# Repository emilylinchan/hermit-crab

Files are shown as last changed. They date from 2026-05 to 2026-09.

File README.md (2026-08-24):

# Hermit Crab 🦀

A WiFi-controlled quadruped walking robot built from scratch — custom 3D-printed chassis, PCB, and ESP32 firmware driving 8 servo leg joints with an OLED face. The long-term goal is an autonomous platform with computer-vision-guided motion planning, built up through multiple hardware and firmware iterations.

<p align="center">
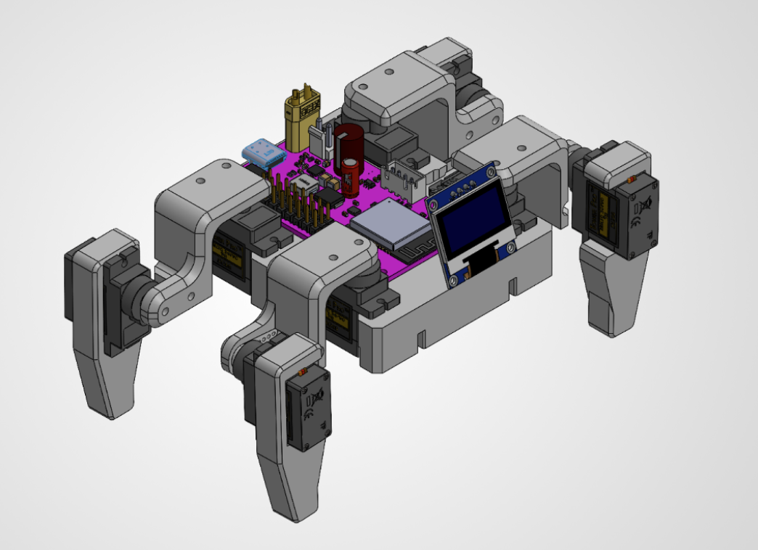
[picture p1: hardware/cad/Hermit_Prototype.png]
Hermit Crab prototype
  
</p>

## Project Structure

```
hermit-crab/
├── firmware/                       
|    ├── main/      # Main ESP32 firmware project
|    └── tests/     # Standalone bring-up sketches (servo calibration, WiFi AP)
|
└── hardware/
    ├── cad/        # Chassis and leg CAD models
    └── pcb/
        ├── drc/    # Design Rule Check for JLC PCB manufacturer
        ├── v1/     # Version 1 board files
        └── v2/     # Version 2 board files
```

- **Firmware** — architecture, controls, and calibration are documented in [`firmware/README.md`](firmware/README.md)
- **Hardware** — component selection and power-system design documented in [`hardware/pcb/Hermit_Hardware_Design.pdf`](hardware/pcb/Hermit_Hardware_Design.pdf)
- **PCB v1** — complete; documented in [`hardware/pcb/v1/README.md`](hardware/pcb/v1/README.md)
- **PCB v2** — in progress; documented in [`hardware/pcb/v2/README.md`](hardware/pcb/v2/README.md)

🎬 **[Watch the video demo of firmware testing](https://youtu.be/UnXPqfklwHU)**

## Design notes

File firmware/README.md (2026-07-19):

# Hermit Crab — Firmware

ESP32 firmware for the Hermit Crab quadruped: C++ (Arduino framework) on FreeRTOS, with a fully data-driven motion engine.

## Hardware Interface

What the firmware expects to be wired up:

| Peripheral | Config |
|---|---|
| Servos | 8× MG90D on pins 13, 14, 23, 16, 17, 18, 19, 33 — order: R1 R2 L1 L2 R4 R3 L3 L4 |
| OLED | SSD1306 128×64 over I2C (SDA 21 / SCL 22, addr `0x3C`) |
| WiFi | AP mode, SSID `HermitCrab`, UI at `http://192.168.0.1` |
| Serial | 115200 baud CLI |

**NOTE:** The MG90D's full 500–2500 µs pulse range spans 270° of travel. The firmware attaches the servos at 833–2167 µs, trimming ~333 µs per side so that the code's 0–180° range maps onto the physically centered 180° of the servo. Keyframes also stay in the 0–180 units and the extreme ends of travel are never commanded.

## Architecture

Four FreeRTOS tasks across both cores. Commands from any source funnel through a single depth-1 queue (`xQueueOverwrite` — newest command always wins), and all physical servo motion flows through one interpolator task.

```mermaid
flowchart TD
    A[Web browser<br/>WiFi AP 192.168.0.1] --> W[webServerTask<br/>Core 0]
    B[Serial monitor<br/>115200 baud CLI] --> S[serialTask<br/>Core 0]
    W --> Q[commandQueue<br/>depth 1, overwrite]
    S --> Q
    Q --> M[motionTask<br/>Core 1, priority 2]
    M -->|setServoTarget| I[interpolatorTask<br/>Core 1, priority 3]
    I --> SV[8× servos<br/>50 Hz PWM]
    M --> O[OLED face<br/>displayMutex]
```

| Task | Core | Priority | Job |
|---|---|---|---|
| `webServerTask` | 0 | 1 | Serves the web UI, parses `/cmd`, `/motor`, `/status` |
| `serialTask` | 0 | 1 | Serial CLI: movements, direct motor control, subtrim |
| `motionTask` | 1 | 2 | The state machine — plays sequences by setting servo targets |
| `interpolatorTask` | 1 | 3 | 50 Hz tick that glides every servo toward its target at a capped speed |

### Single-Owner Servo Model

There is no servo mutex, by design. `servoTarget[]` may be written from any task via `setServoTarget()`, but **servo hardware is written only by `interpolatorTask`** — the single owner. Poses and gaits never touch the hardware; they declare where servos should *end up*, and the interpolator moves them there at up to `servoMaxSpeed` (600 deg/s default), producing smooth motion and eliminating write races structurally instead of locking around them.

The one exception is boot: `setServoImmediate()` snaps all servos to 90° once, staggered 5 ms apart to spread inrush current, before any task exists.

### Data-Driven Motion

Every movement is a table of `Keyframe`s — 8 target angles (or `NC` = "no change") plus a duration — wrapped in a `Sequence` with playback flags:

```cpp
static const Keyframe WAVE_FRAMES[] = {
  //  R1   R2   L1   L2   R4   R3   L3   L4    ms
  { {135,  45,  45, 135,   0, 180,   0, 180}, 200 },  // stand
  { {170,  NC,  NC, 165,  NC,  NC,  NC,  NC}, 250 },  // shift weight back-right
  ...
};
const Sequence SEQ_WAVE = { WAVE_FRAMES, FRAME_COUNT(WAVE_FRAMES), 3, 4, false, true, false };
```

Sequence flags control playback: `loopStart`/`repeatCount` replay a section, `isGait` marks continuous held-state cycles (walking, turning), `standAtEnd` glides back to the stand posture when finished (used by one-shot poses), and `sticky` parks in the state after completion (used by static poses). Two generic engines (`playPose`, `playGaitCycle`) play everything; a lookup table maps states to sequences.

**Adding a new movement** touches four data tables and zero functions: a state in the `MovementState` enum, a frames array + `Sequence` in `movement-sequences.cpp`, a row in `SEQUENCE_TABLE`, a row in `COMMAND_TABLE`, and a row in `FACE_TABLE`.

### Interruption and Safety

Animations poll the command queue *inside* their frame delays (`interruptibleDelay` for poses, `pressingCheck` for gaits), so a new command preempts mid-animation instead of waiting for the sequence to finish. Aborted gaits recover gracefully to the stand posture.

The web D-pad drives gaits as **held** commands: the browser re-sends the command every 200 ms while the button is held, and a firmware hold watchdog (`HOLD_TIMEOUT_MS`, 600 ms) stops the robot if refreshes stop arriving — a closed browser, a dropped WiFi link, or a finger sliding off the button can't leave the robot walking into a wall. The web UI adds its own layers: pointer capture so release always registers, plus auto-stop when the tab is hidden or loses focus. Serial gait commands are not held and run until `stop`.

## Controls

### Web UI

Connect to the `HermitCrab` WiFi access point and open `http://192.168.0.1`. The interface has a hold-to-drive D-pad, a stop button, one-tap pose buttons, and per-servo sliders for direct motor control.

### Serial CLI (115200 baud)

```
rest, stand, walk, back, left, right,     movement & pose commands
wave, dance, swim, point, pushup, bow,
cute, freaky, worm, shake, shrug,
dead, crab, stop

<m> <angle>        direct motor (e.g. "3 90")
all <angle>        all motors at once
subtrim            show trim values
subtrim <m> <v>    trim motor m by v degrees (-90..+90)
subtrim reset      zero all trims
subtrim save       print a code line to paste back into the sketch
```

### HTTP API

| Endpoint | Description |
|---|---|
| `GET /cmd?c=<command>` | Any command string from the table above |
| `GET /motor?i=<0-7>&a=<0-180>` | Direct motor write |
| `GET /status` | JSON state + live servo positions |

`/status` returns live interpolated positions, intended as the hook for future scripting and the Raspberry Pi / ROS 2 bridge:

```json
{"state":7,"name":"wave","pos":[135,45,45,135,0,180,0,80]}
```

## Calibration

Mechanical assembly never puts every leg segment at a perfect neutral, so each servo has a **subtrim** offset applied at hardware-write time. The workflow: run the robot, adjust live over serial (`subtrim 3 -4`), then `subtrim save` prints the `servoSubtrim[8]` initializer to paste into the sketch permanently.

## Directory Layout

```
firmware/
├── main/
|    ├── main.ino                    # Tasks, state machine, interpolator, web/serial handlers
|    ├── movement-sequences.h        # Servo layout, state enum, Keyframe/Sequence model
|    ├── movement-sequences.cpp      # All pose & gait data tables + the playback engines
|    ├── web.h                       # The web UI (single self-contained HTML page in PROGMEM)
|    └── face-bitmaps.h / .cpp       # OLED face bitmaps (X-macro list, image2cpp output)
|
└── tests/
     ├── servo/mg90d-servo-test.ino  # Standalone sketch for bring-up/calibration of servos
     └── wifi/wifi-test.ino          # Standalone sketch to verify the ESP32 WiFi AP in isolation
```

## Hardware Status
 
The firmware currently runs on an **ESP32 WROOM-32E dev board** for testing while the custom ESP32-S3 PCB is being built. The pin assignments above reflect the dev board wiring and will change when the firmware moves to the S3 board.
 
## Roadmap
 
- Orientation sensing (IMU) once PCB is done
- Forward kinematics for foot-position telemetry over `/status`
- Raspberry Pi 5 + ROS 2 / MoveIt 2 as a high-level planner, with the ESP32 as a real-time joint-space executor
- Camera + computer-vision-guided motion planning

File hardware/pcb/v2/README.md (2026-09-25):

# Hermit V2 PCB

## Background

Version 1 successfully validated the core power architecture. The ESP32 was able to be powered from both USB and battery, and the 3.3 V rail reliably powered all I2C peripherals. A temporary block-terminal test point inserted in the battery input path also enabled current consumption measurements, which matched the original design expectations. As a result, no functional changes to the power system were required.

### Issues with V1

- ESP32 received power, but was not recognized as a valid device by USB.
- Data lines were not properly impedance matched (the USB D+ and D− signals must be routed as a 90Ω ± 10% differential pair).

## Changes in V2

- Added power indicator LEDs for immediate visual confirmation of each power rail, eliminating the need to probe with a DMM during bring-up.
- Removed the temporary block-terminal current measurement point used during V1 validation.
- Optimized component placement and routing to reduce the overall PCB footprint.
- Moved the ESP32 further inward on the board so the antenna no longer overhangs the PCB as it did in V1, improving mechanical integration and simplifying the CAD enclosure design.
- Used layer stackup information from our fabricator ([JLC PCB](https://jlcpcb.com/impedance)) and Altium's trace impedance calculator to determine the exact trace width and spacing needed to meet USB impedance requirements.

## Altium Layouts

<table>
  <tr>
    <td align="center">
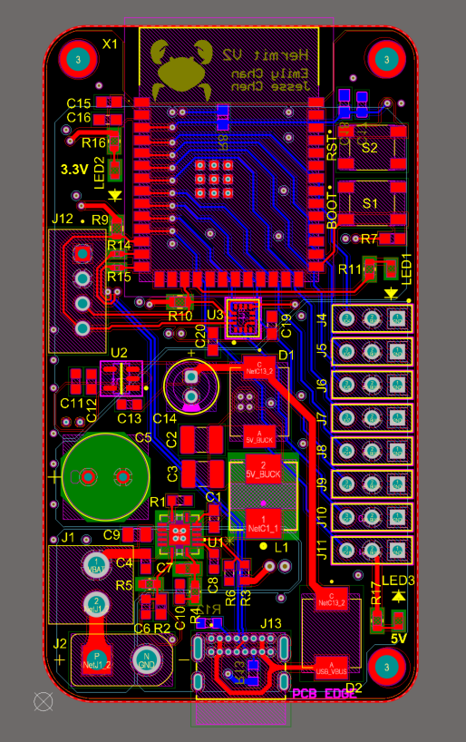
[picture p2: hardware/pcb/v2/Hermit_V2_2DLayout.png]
2D Layout
      <br>
      2D Layout
    </td>
    <td align="center">
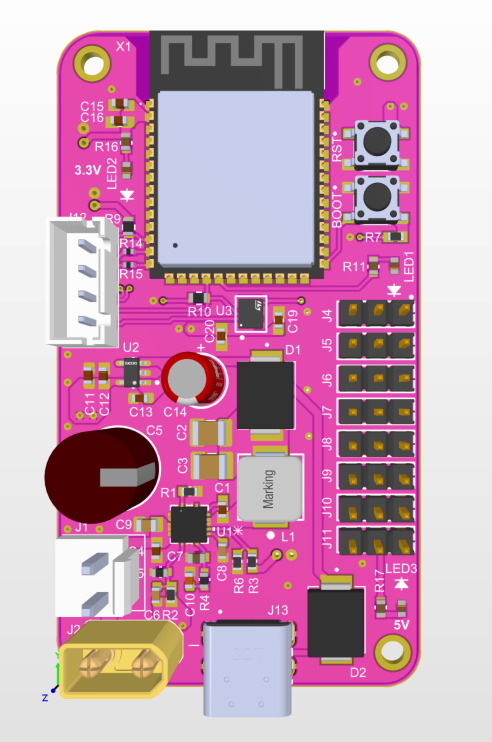
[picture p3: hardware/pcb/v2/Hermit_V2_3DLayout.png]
3D Layout
      <br>
      3D Layout
    </td>
  </tr>
</table>

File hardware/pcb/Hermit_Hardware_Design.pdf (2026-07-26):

Hermit Crab — Hardware Design · 1

# Hermit Crab

## Hardware Design Documentation

Emily Chan and Jesse Chen
Quadruped robotics platform · ESP32-S3 · 2S LiPo power system

This document captures the power-electronics and control-hardware design decisions behind the Hermit Crab robot. It begins with the servo motors and battery that define the system's load and energy budget, then walks through the 5 V buck converter and its component selection, the 3.3 V logic supply, the ESP32-S3 microcontroller and its USB programming interface, power source arbitration between battery and USB, and the onboard IMU and OLED display.

## 1. Servo Motors — MG90D Digital Micro Servo

The eight leg joints are driven by MG90D digital micro servos. Their peak current draw sets the sizing of the 5 V buck converter, and their PWM control scheme defines the timing requirements for the ESP32-S3.

Electrical Characteristics

- Operating voltage: 4.8 – 6.6 V
- Static current: 5 – 6 mA
- No-load current: 220 mA
- Stall (blocking) current: 800 mA + 10% ≈ 880 mA

PWM Control

- Rotation direction: CCW
- Pulse width range: 500 – 2500 µs – Origin position: 500 µs
– Neutral position: 1500 µs
– End position: 2500 µs
- Operating frequency: 50 – 330 Hz
– Standard application: 50 Hz (20 ms PWM frame)
- The output angle is set by the high-time of the pulse — the ESP32-S3 generates one PWM channel per servo.

Impact on Power Design

Eight servos, each with an 880 mA stall current, produce a worst-case load of approximately 7.0 A. Allowing additional headroom for the ESP32 and other onboard peripherals, the 5 V rail is designed to supply up to 8 A. In practice, all eight servos are unlikely to stall simultaneously, so the typical current draw is significantly lower; however, the power rail is sized to accommodate this worst-case scenario.

## 2. Battery — Fytoo 2S 2000 mAh (XT30)

The robot is powered by a Fytoo 2S 2000 mAh 15C LiPo pack. This higher capacity compared to a smaller pack allows for significantly greater runtime, while its 15C rating still supplies the servo load with wide margin. The trade-off is added weight, which the chassis and leg servos must carry.

Specifications

- Configuration: 2S1P / 7.4 V nominal / 2 cell
- Capacity: 2000 mAh
- Continuous discharge: 15C
- Discharge plug: XT30
- Weight: 89g

Discharge Headroom

The C-rating sets the maximum safe current the pack can source:

- Continuous: 15C × 2.0 Ah ≈ 30 A
This is well above the ~8 A worst-case system load, so the pack is never current-limited and voltage sag under a stall event is minimal.

Runtime Calculations

Stored energy at nominal voltage:

- 2.0 Ah × 7.4 V ≈ 14.8 Wh
Runtime is estimated as usable capacity divided by average current draw. Using 80% usable capacity (to avoid over-discharging the cells) and adding ~0.3 A for logic and sensors, the runtime across load scenarios is:
- Typical gait (~400 mA/servo avg): ~3.5 A total → roughly 27 – 28 minutes.
- All servos no-load (220 mA each): ~2.1 A total → roughly 45 minutes.
- Worst case, all servos stalled (880 mA each): ~7.3 A total → roughly 13 minutes.

## 3. 5 V Buck Converter — TPS54821

The main system rail is generated by a TPS54821 synchronous step-down converter, sized to drive eight servos plus the logic electronics from a 2S LiPo battery.

Power Budget

- Servos: 8 × 1 A peak
- ESP32-S3: 500 mA peak during Wi-Fi transmission spikes
- IMU and OLED: negligible

Design Requirements

- Input range: 6 V – 8.4 V (2S LiPo)
- Output: 5 V @ 8 A

Datasheet: https://www.ti.com/lit/ds/symlink/tps54821.pdf

Reference Schematic

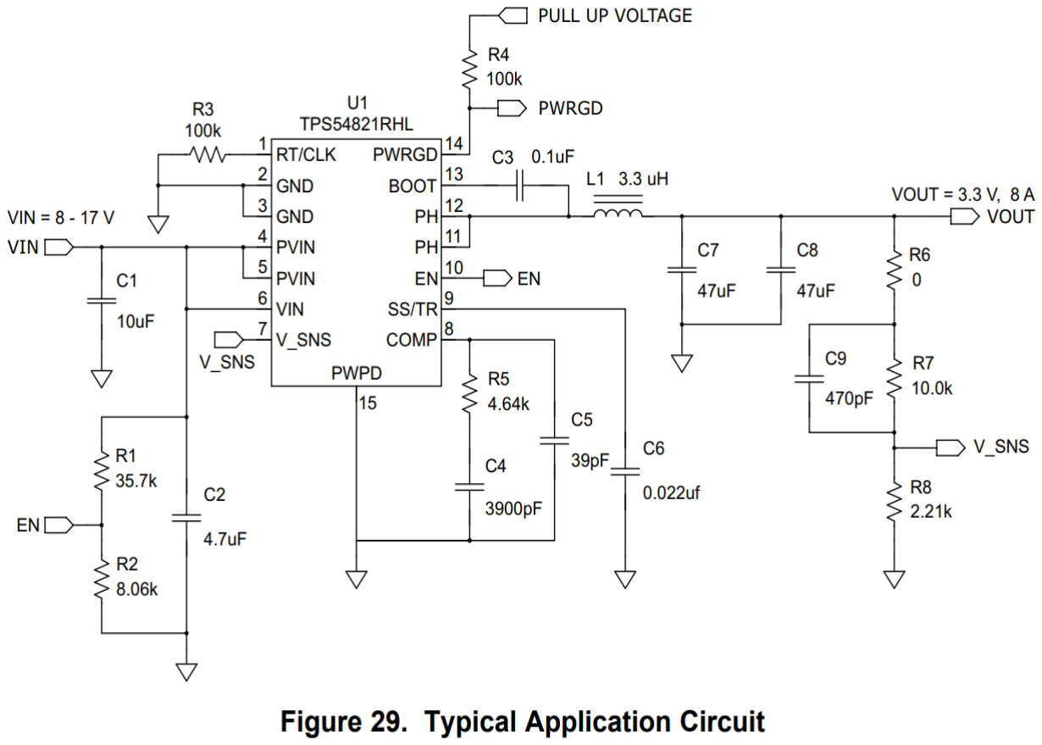
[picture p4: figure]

TPS54821 buck converter, modelled on the datasheet application example.

Design Summary

Parameter | Value
Output voltage (Vout) | 5 V
Output current | 8 A
Transient response, 4 A load step (ΔIout) | ΔVout = 0.35 V (7%)
Input voltage (Vin) | 6.0 V (empty) 7.4 V (nominal) 8.4 V (fully charged)
Reference voltage | 0.6 V
Output voltage ripple | 33 mV p-p
Start input voltage (rising Vin) | 6.528 V
Stop input voltage (falling Vin) | 6.193 V
Operating frequency | 480 kHz

Switching Frequency

The switching frequency sets a trade-off between size and efficiency:

- Higher frequency → smaller solution size, since lower inductance and output-capacitor values can be used.
- Lower frequency → higher efficiency and less heat.
A moderate 480 kHz switching frequency was selected to balance compact size against efficient operation, matching the datasheet application example.

Reference: https://www.ti.com/lit/wp/slyy193c/slyy193c.pdf

Undervoltage Lockout (UVLO)

Undervoltage lockout matters for the 2S LiPo pack because over-discharging causes permanent capacity loss. The turn-on and turn-off thresholds are set by the R1/R2 divider on the EN pin.

Turn-on threshold — 6.528 V

- The converter will not begin switching until the battery voltage rises above this level.
- Prevents the converter from attempting to run when the battery is too low. Turn-off threshold — 6.193 V
- Once running, the converter keeps switching until the battery falls below this level.
- Shuts down below the threshold to avoid undervoltage stress on the cells.
Hysteresis window
- The gap between the two thresholds stops the converter from rapidly cycling on and off when the battery hovers near the limit.
- Set by the R1/R2 divider feeding the EN pin: R1 = 35.7 kΩ, R2 = 8.06 kΩ (matching the application example).

Reference: https://www.ti.com/document-viewer/lit/html/SSZTAG8

Bootstrap Capacitor

- A 0.1 µF ceramic capacitor (C3) is connected between the BOOT and PH pins for proper high-side gate drive.
- An X5R or better dielectric grade is recommended.

Slow-Start Capacitor

The slow-start capacitor sets the minimum time for the output to ramp to its nominal value at power-up.

For this design the soft-start time is not critical, since the 2 × 47 µF output capacitance charges to 5 V without drawing much current. Using the TPS54821 slow-start current of Iss = 2.3 µA and a target ramp of 6 ms:

C6 = 22 nF was selected (matching the application example).

Output Inductor

KIND is the coefficient describing inductor ripple current relative to maximum output current; typical values range from 0.1 to 0.3. A value of 0.3 was chosen here.

The calculated minimum is L1 = 1.76 µH. A larger standard 3.3 µH value was selected to lower ripple current and match the application example.

Reference: https://www.ti.com/lit/ta/ssztap6/ssztap6.pdf

Output Capacitor

The output capacitor must supply load transients until the control loop responds:

- The regulator typically needs two or more clock cycles to detect a load change and adjust the duty cycle.

- The output capacitance must supply the current difference over those two cycles while limiting output voltage sag to a tolerable level.

The calculated minimum is Co = 47.6 µF. To account for capacitance de-rating from aging, temperature, and DC bias, a conservative 2 × 47 µF was chosen.

Input Capacitor

The TPS54821 requires a high-quality X5R or X7R ceramic decoupling capacitor of at least 4.7 µF effective capacitance on each of the PVIN and VIN pins.

C1 = 10 µF and C2 = 4.7 µF were selected (matching the application example).
Output Voltage Feedback Divider
The R7/R8 divider sets the output voltage:

With R7 = 10 kΩ, R8 calculates to 1.36 kΩ, rounded to R8 = 1.37 kΩ — the nearest standard 1% value.

Compensation Network

An RC network stabilizes the converter's internal error amplifier and feedback control loop.

- Compensation resistor (Rc = R5 = 4.64 kΩ): in series with the compensation capacitor to the COMP pin; sets mid-band gain, loop crossover frequency, and transient response.
- Compensation capacitor (Cc = C4 = 3900 pF): creates a low-frequency pole that boosts phase margin at crossover for stability.
- High-frequency capacitor (Cp = C5 = 39 pF): from COMP to ground; adds a high-frequency pole to attenuate switching noise and gain spikes.
- Feed-forward capacitor (Cff = C9 = 470 pF): across the top feedback resistor; adds a phase-lead zero that improves phase margin and transient response and attenuates high-frequency output noise.
Because the operating conditions closely match the application example, the same compensation values were used.

## 4. 3.3 V Logic Supply — AP2112K-3.3TRG1

A low-dropout regulator generates the 3.3 V logic rail from the 5 V system supply.

Specifications

- Input: 2.5 – 6 V
- Output: 3.3 V @ 0.6 A
- Enable: tie pin 3 (EN) to VIN for normal operation (logic high).

Datasheet: https://www.diodes.com/assets/Datasheets/AP2112.pdf

## 5. Microcontroller — ESP32-S3-WROOM

The ESP32-S3-WROOM is the main controller. To keep the supply stable through power-up, an RC delay on the EN pin is recommended: R = 10 kΩ, C = 1 µF, giving roughly a 10 ms delay.

Datasheet: https://documentation.espressif.com/esp32-s3-wroom-1_wroom-1u_datasheet_en.pdf

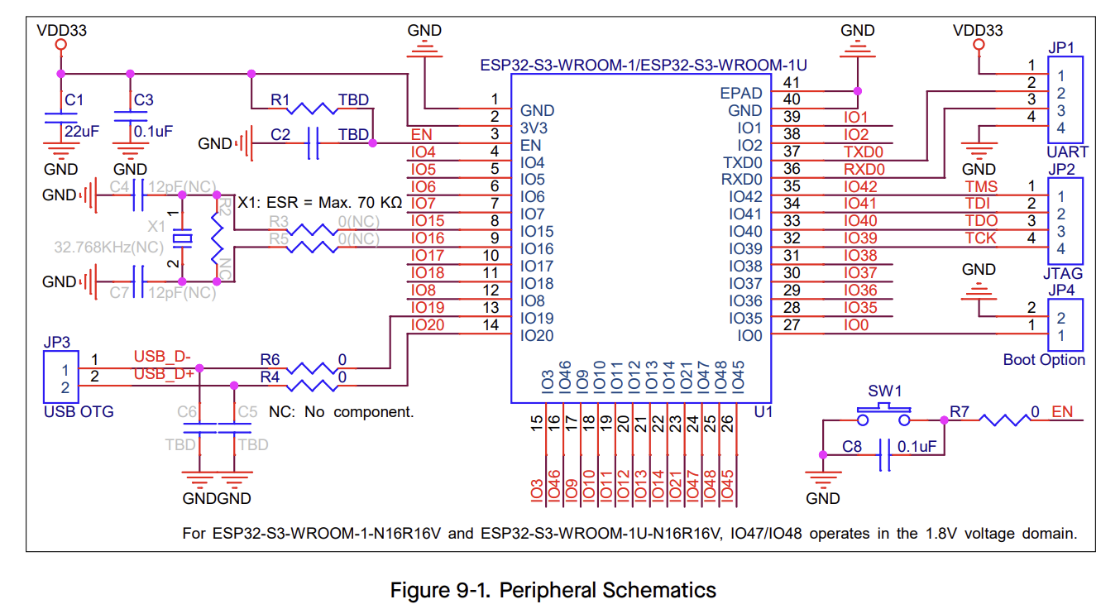
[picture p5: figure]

ESP32-S3-WROOM typical application circuit reference.

## 6. USB On-The-Go (OTG) Interface

The native USB-OTG interface provides serial communication and firmware flashing without an external USB-to-UART bridge.

Connection & Operation

- Data pins: fixed to GPIO 19 (D−) and GPIO 20 (D+).
- USB device mode: acts as a virtual COM port for serial communication and easy flashing.
- Cabling: a USB cable plugs directly into the native USB-OTG port, bypassing any external bridge chip.

Boot & Download Mode

The boot/flash header controls GPIO0, which selects the boot mode at reset:

- GPIO0 HIGH at reset → normal boot.
- GPIO0 LOW at reset → bootloader / download mode (required for flashing). Without auto-reset circuitry, entering download mode is a manual sequence:
1. Hold BOOT.
2. Press RESET.
3. Release RESET.
4. Release BOOT.
Note: GPIO2 must also be left floating or driven low to enter the serial bootloader.

Boot mode selection: https://docs.espressif.com/projects/esptool/en/latest/esp32/advanced-topics/boot-mode-selection.html

USB Type-C Configuration (UFP)

- Power direction: the port sinks power (VBUS), drawing from the host or charger.
- CC configuration: a UFP applies 5.1 kΩ pull-down resistors (Rd) on both CC1 and CC2 so the system recognizes it as a device.

Reference: https://www.ti.com/lit/wp/slyy109b/slyy109b.pdf

Series Data Resistors

Many ESP32-S3 development boards place 22 Ω resistors between D+/D− and GPIO 19/20. These are highly recommended but not strictly required. They:

- Dampen ringing and improve signal integrity.
- Reduce EMI.
- Help with impedance matching.

## 7. Power Source Selection — Schottky OR-ing

Schottky OR-ing selects between USB and battery power automatically:

- USB-C powers the board when plugged in.
- LiPo battery powers the board when unplugged.
- No risk of back-feeding USB into the battery or the battery into USB.

LDO Dropout Headroom

- AP2112K dropout is typically 250 mV @ 600 mA.
- This leaves sufficient headroom even after the Schottky diode drop.

Servo Power Routing

Note: servos must not be powered from the OR-ed 5V system rail — the worst-case 8 A load exceeds the Schottky diode rating. Instead, servos are powered directly from the 5 V buck converter output.

## 8. IMU — LSM6DSO32

A 6-axis IMU provides motion sensing for the platform.

Specifications

- Supply: 3.3 – 5 V
- Sensors: 3-axis accelerometer + 3-axis gyroscope.
- Interface: I²C — external pull-up resistors required, as the ESP32 does not provide them.

Configuration

- SA0 (address LSB): set to 1 (soldered).
- CS: set to 1 to enable I²C communication (mode 1).
- See datasheet page 24 for pin connections.

Datasheet: https://www.st.com/resource/en/datasheet/lsm6dso32.pdf

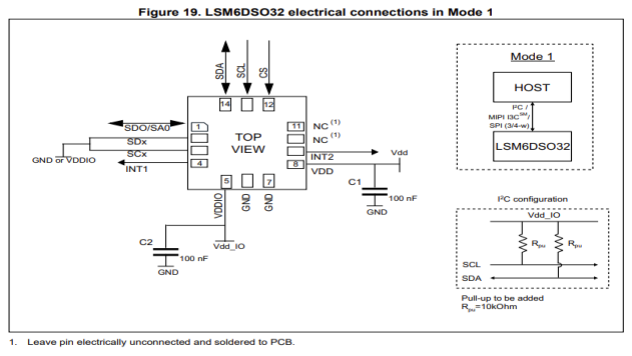
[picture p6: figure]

LSM6DSO32 I²C wiring reference.

## 9. OLED Display — SSD1306

An SSD1306-based OLED displays Hermit’s facial expressions.

Specifications

- Supply: 3.3 – 5 V
- Interface: I²C — shares the same bus as the IMU.

Datasheet: https://cdn-shop.adafruit.com/datasheets/SSD1306.pdf

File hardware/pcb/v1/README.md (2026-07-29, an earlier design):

# Hermit V1 PCB

<p align="center">
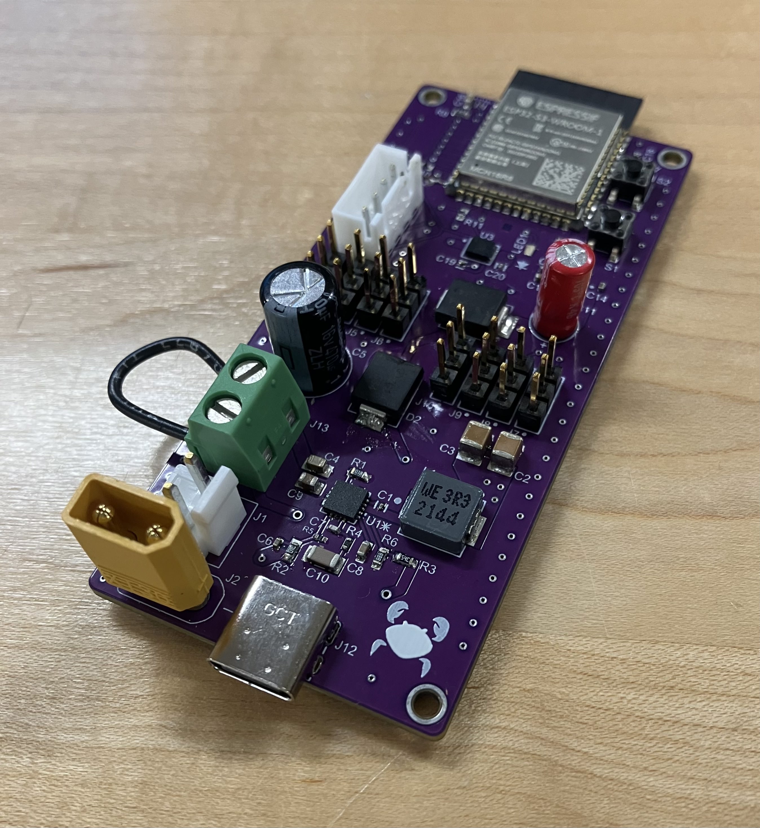
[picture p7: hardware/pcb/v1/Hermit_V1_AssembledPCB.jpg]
Hermit V1 assembled PCB
  
</p>

Custom 4-layer power and control PCB for the Hermit Crab project, designed in Altium Designer. The board is powered by a 2S LiPo battery and integrates an ESP32-S3 with cascaded 5V buck and 3.3V LDO regulation, IMU and OLED peripherals over I2C, and Schottky diode OR-ing to allow USB-powered development.

## Design Overview

- **MCU:** ESP32-S3
- **Power input:** 2S LiPo battery
- **Regulation:** Cascaded 5V buck converter followed by a 3.3V LDO
- **Peripherals:** IMU and OLED display over I2C
- **USB development support:** Schottky diode OR-ing between battery and USB power rails
- **Layer stackup:** 4 layers

## Version 1 Notes

This is the first revision of the board, built to validate the overall design before committing to further iterations. A large test point (the green block terminal) was included specifically to break out and measure current draw, so the current requirements of the servo motors can be precisely characterized to inform regulator and battery sizing on future revisions.

The bare board was fabricated by JLCPCB. Components were purchased from Digikey (see [BOM](Hermit%20V1_BOM.xlsx)) and hand-assembled/soldered.

## Files

| File | Description |
| --- | --- |
| `Hermit V1_BOM.xlsx` | Bill of materials |
| `Hermit_V1_AssembledPCB.heic` | Photo of the assembled board |
| `Hermit_V1_GerberX2.zip` | Fabrication files |
| `Hermit_V1_Schematic.pdf` | Full schematic |

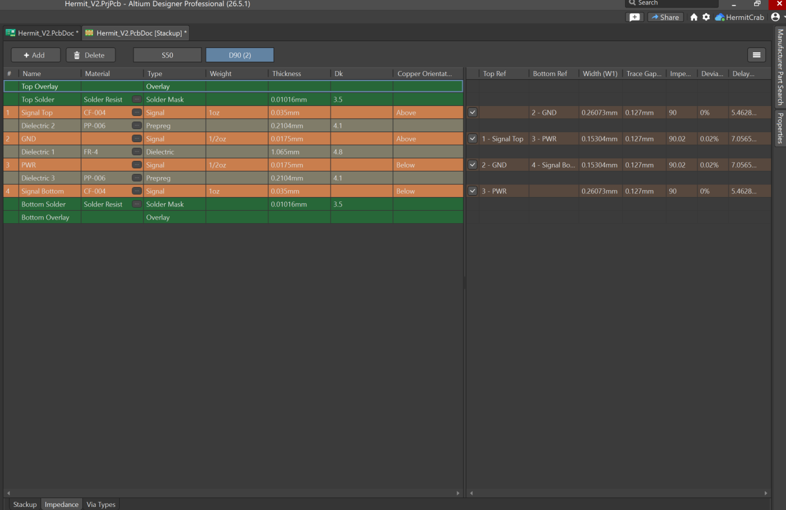
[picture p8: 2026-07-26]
hardware/pcb/v2/Hermit_V2_Impedance.png

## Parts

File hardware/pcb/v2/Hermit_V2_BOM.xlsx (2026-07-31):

Name | Designator | Description | Purpose | Manufacturer Part Number | Quantity
100nF | C1, C16, C18, C19, C20 | 0.1 µF ±10% 25V Ceramic Capacitor X7R 0603 (1608 Metric) | High frequency decoupling capacitor | C0603C104K3RACTU | 5
47uF | C2, C3 | SMD capacitor X7R(EIA) with capacitance 47uF Tol.10%. Rated voltage 10Vdc 125C | Buck converter output capacitors | GRM32ER71A476KE15L | 2
10uF | C4, C12 | 10 µF ±20% 10V Ceramic Capacitor X5R 0603 (1608 Metric) | Buck converter and LDO decoupling capacitor | GRM188R61A106ME69D | 1
470uF | C5 | 470 µF 16 V Aluminum Electrolytic Capacitors Radial, Can 8000 Hrs @ 105°C | Buck converter output bulk capacitor | 16ZLH470MEFCT78X11.5 | 1
470pF | C6 | 470 pF ±5% 50V Ceramic Capacitor C0G, NP0 0603 (1608 Metric) | Buck converter feed-forward capacitor | CL10C471JB8NNNC | 1
39pF | C7 | 39 pF ±5% 50V Ceramic Capacitor C0G, NP0 0603 (1608 Metric) | Buck converter compensation capcitor | C0603C390J5GACTU | 1
0.022uF | C8 | 0.022 µF Â±10% 16V Ceramic Capacitor X7R 0603 (1608 Metric) | Buck converter soft start capacitor | CL10B223KO8WPNC | 1
4.7uF | C9 | 4.7 µF ±10% 25V Ceramic Capacitor X5R 0805 (2012 Metric) | Buck converter input capacitor | CL21A475KAQNNNE | 1
3900pF | C10 | 3900 pF ±10% 50V Ceramic Capacitor X7R 0603 (1608 Metric) | Buck converter compensation capcitor | 0603B392K500CT | 1
100µF | C14 | WCAP-ATUL Aluminum Electrolytic Capacitor, Radial, THT, 5mm x 11mm, 100µF, 10V | LDO input bulk capacitor | 860040272001 | 1
1uF | C11, C13, C17 | 1 µF ±10% 16V Ceramic Capacitor X7R 0603 (1608 Metric) | LDO and ESP32 decoupling capacitors | C0603C105K4RACTU | 3
22uF | C15 | 22 µF ±20% 6.3V Ceramic Capacitor X5R 0603 (1608 Metric) | ESP32 input capacitor | GRM188R60J226MEA0J | 1
SS34 | D1, D2 | Diode Schottky 40 V 3A Surface Mount SMC (DO-214AB) | 5V power selection mechanism | SS34 | 2
B2P-VH | J1 | 2 Position Adapter Connector Receptacle, Female Sockets To Receptacle, Female Sockets 0.156 (3.96mm) | Power switch connector | B2P-VH | 1
XT30PW-M | J2 | Socket; DC supply; XT30; male; PIN: 2; on PCBs; THT; yellow; 15A; 500V | LiPo battery connector | XT30UPB-M | 1
TSW-103-22-G-S | J4, J5, J6, J7, J8, J9, J10, J11 | Conn Unshrouded Header HDR 3 POS 2.54mm Solder ST Thru-Hole Bulk | Servo motor connectors | TSW-103-07-F-S | 8
B4B-XH-A | J12 | Connector Header Through Hole 4 position 0.098 (2.50mm) | OLED connector | B4B-XH-A | 1
USB4085-GF-A | J13 | USB-C (USB TYPE-C) USB 2.0 Receptacle Connector 24 (16+8 Dummy) Position Through Hole, Right Angle, low cost, 3.46mm profile, 16 pin, horizontal, Top mount | USB-C port for serial communication and power | USB4085-GF-A | 1
3.3uH | L1 | 3.3 µH Shielded Molded Inductor 5 A 30mOhm Max 2-SMD | Buck converter output inductor | 74437346033 | 1
D2, D3 | LED2, LED3 | Blue 470nm LED Indication - Discrete 2.85V 0603 (1608 Metric) | Power LED | KB EELP41.12-P1R2-36-3X4X-5-R18 | 2
D1 | LED1 | Red 631nm LED Indication - Discrete 2V 0603 (1608 Metric) | ESP32 GPIO controllable LED for debugging | LTST-C190KRKT | 1
100kΩ | R1 | 100 kOhms ±0.25% 0.1W, 1/10W Chip Resistor 0603 (1608 Metric) Thin Film | Buck converter switching frequency | RT0603CRE07100KL | 1
35.7kΩ | R3 | Res Thin Film 0603 35.7K Ohm 0.1% 0.1W(1/10W) ±25ppm/C Epoxy Pad SMD T/R | Buck converter UVLO configuration | RT0603BRD0735K7L | 1
4.64kΩ | R4 | 4.64 kOhms ±1% 0.1W, 1/10W Chip Resistor 0603 (1608 Metric) Moisture Resistant Thick Film | Buck converter compensation RC network | RC0603FR-074K64L | 1
1.37kΩ | R5 | 1.37 kOhms ±1% 0.1W, 1/10W Chip Resistor 0603 (1608 Metric) Moisture Resistant Thick Film | Buck converter Vout configuration | RC0603FR-071K37L | 1
8.06kΩ | R6 | 8.06 kOhms ±0.1% 0.1W, 1/10W Chip Resistor 0603 (1608 Metric) - Thin Film | Buck converter UVLO configuration | RT0603BRD078K06L | 1
220Ω | R11, R16, R17 | 220 Ohms ±1% 0.1W, 1/10W Chip Resistor 0603 (1608 Metric) Thick Film | ESP32 LED limiting resistor | RC0603FR-13220RL | 1
4.7kΩ | R9, R10 | 4.7 kOhms ±0.05% 0.1W, 1/10W Chip Resistor 0603 (1608 Metric) Anti-Sulfur, Automotive AEC-Q200 Thin Film | I2C pull-up resistors | RG1608N-472-W-T1 | 2
5.1kΩ | R12, R13 | Res Thick Film 0603 5.1K Ohm 1% 0.1W(1/10W) ±100ppm/°C Epoxy Pad SMD T/R | ESP32 USB OTG pull-down resistors | RC0603FR-105K1L | 2
22Ω | R14, R15 | 22 Ohms ±1% 0.063W, 1/16W Chip Resistor 0402 (1005 Metric) Automotive AEC-Q200 Thick Film | USB data line impedance matching | CRCW040222R0FKED | 2
BOOT | S1 | Tactile Switch SPST-NO Top Actuated Surface Mount | ESP32 button for BOOT function | PTS647SM38SMTR2 LFS (https://www.digikey.ca/en/products/detail/c-k/PTS647SM38SMTR2-LFS/9649861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) | 1
RESET | S2 | Tactile Switch SPST-NO Top Actuated Surface Mount | ESP32 button for RESET function | PTS647SM38SMTR2 LFS (https://www.digikey.ca/en/products/detail/c-k/PTS647SM38SMTR2-LFS/9649861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) | 1
TPS54821RHLR | U1 | 4.5-V to 17-V, 8-A synchronous buck converter with hiccup current limit 14-VQFN -40 to 125 | Downstep 7.4V to 5V | TPS54821RHLT | 1
AP2112K-3.3TRG1 | U2 | AP2112 Series 0.6 A 3.3 V Fixed Output SMT LDO Linear Regulator - SOT23-5 | Downstep 5V to 3.3V | AP2112K-3.3TRG1 | 1
LSM6DSO32TR | U3 | Accelerometer and 3D Gyroscope 3D Always-On 1.71V to 3.6V 0.55mA 14-Pin LGA T/R | Accel and gyro measurements | LSM6DSO32XTR | 1
ESP32-S3-WROOM-1-N16R8 | X1 | Bluetooth, WiFi 802.11b/g/n, Bluetooth v5.0 Transceiver Module 2.4GHz PCB Trace Surface Mount | Logic and control | ESP32-S3-WROOM-1-N16R8 | 1

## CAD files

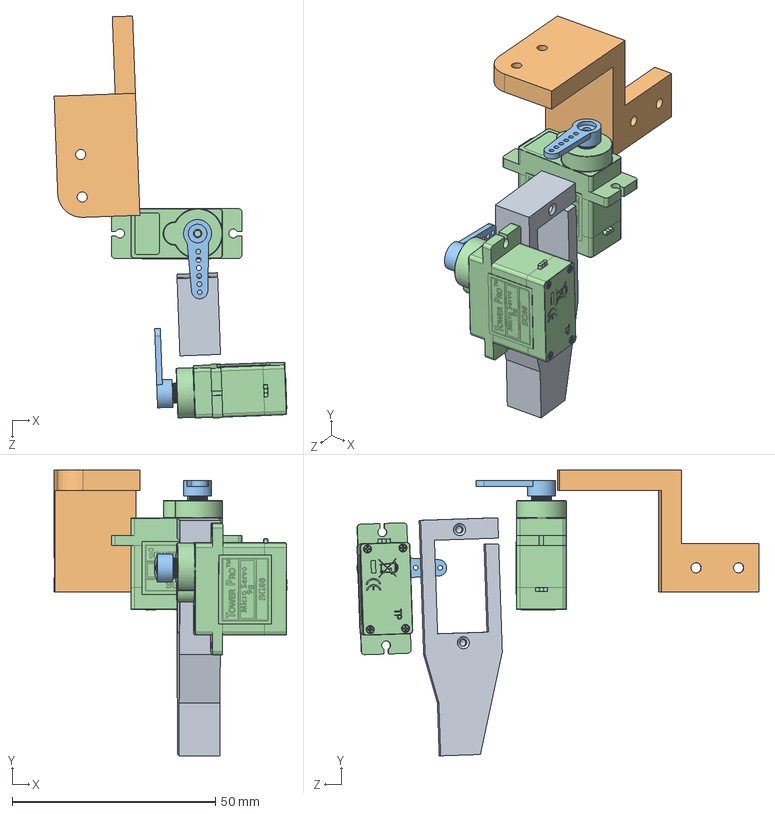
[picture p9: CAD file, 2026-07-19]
hardware/cad/Leg.SLDASM
57.2 x 70.2 x 98.8 mm
SG90 - Micro Servo 9g - Tower Pro x 2
SG90 - Arm x 2
Femur
Foot

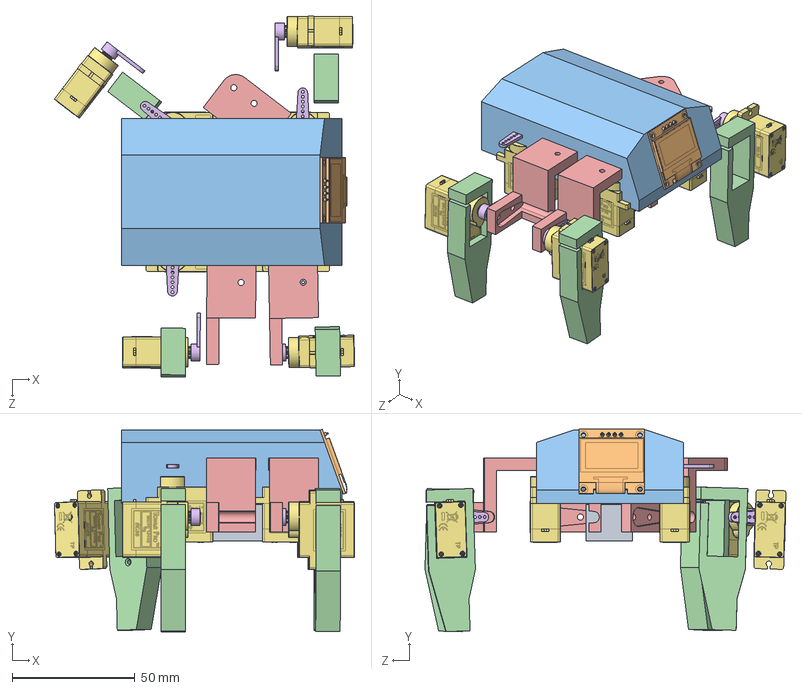
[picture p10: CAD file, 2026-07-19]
hardware/cad/Hermit.SLDASM
122.4 x 82.6 x 147.3 mm
SG90 - Micro Servo 9g - Tower Pro x 8
SG90 - Arm x 8
Femur x 4
Foot x 4
Hermit Top
OLED-128x64-0.96 v1
battery

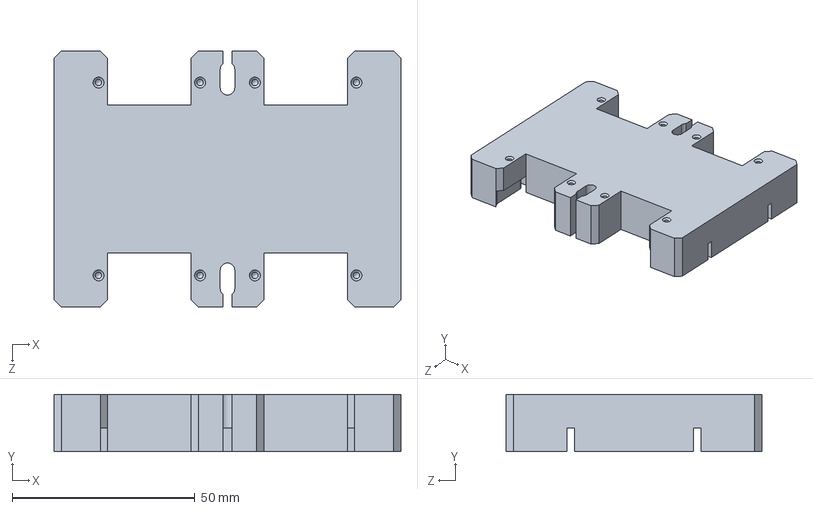
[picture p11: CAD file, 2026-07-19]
hardware/cad/Hermit Chassis.SLDPRT
95.0 x 15.7 x 70.0 mm

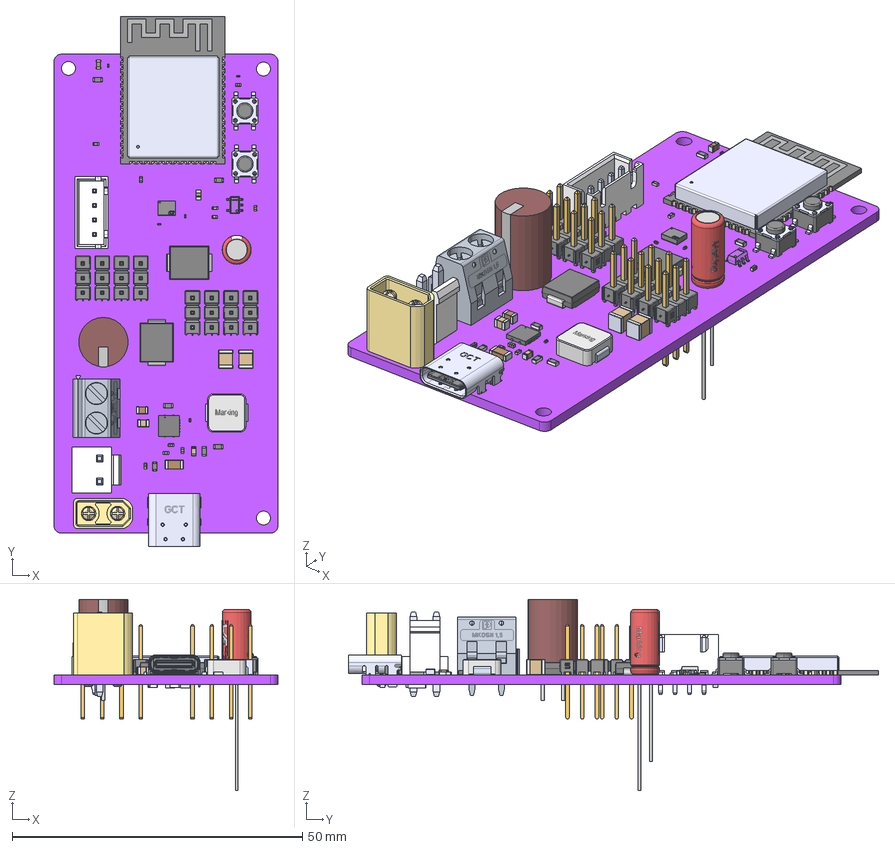
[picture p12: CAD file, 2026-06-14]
hardware/pcb/Hermit_V1/Hermit_V1.step
38.6 x 91.4 x 32.9 mm
5x11x2x0.5 x 2
base x 2
logo x 6
terminals x 6
IC_BODY
IC_LEG x 3
circle
Diodes Incorporated
IC_LEG_MIR4 x 2
pin x 3
USB4085-GF-A_PART2
USB4085-GF-A_PART1_1
Part27^USB4085-GF-A_1
BxB-XH-A_04
_TSW-103-22-G-S_body x 8
_T-1S6-15-TSW-1-22-3-S x 8
Samtec Logo x 8
BxP-VH_2

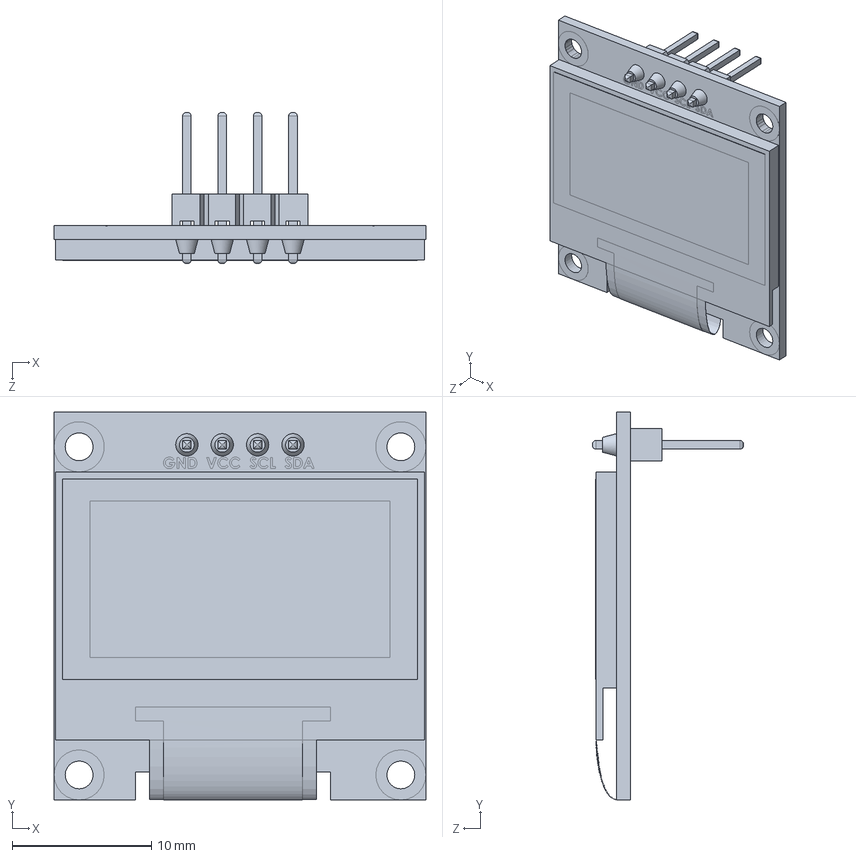
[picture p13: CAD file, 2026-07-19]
hardware/cad/OLED-128x64-0.96 v1.SLDPRT
26.7 x 27.9 x 10.8 mm

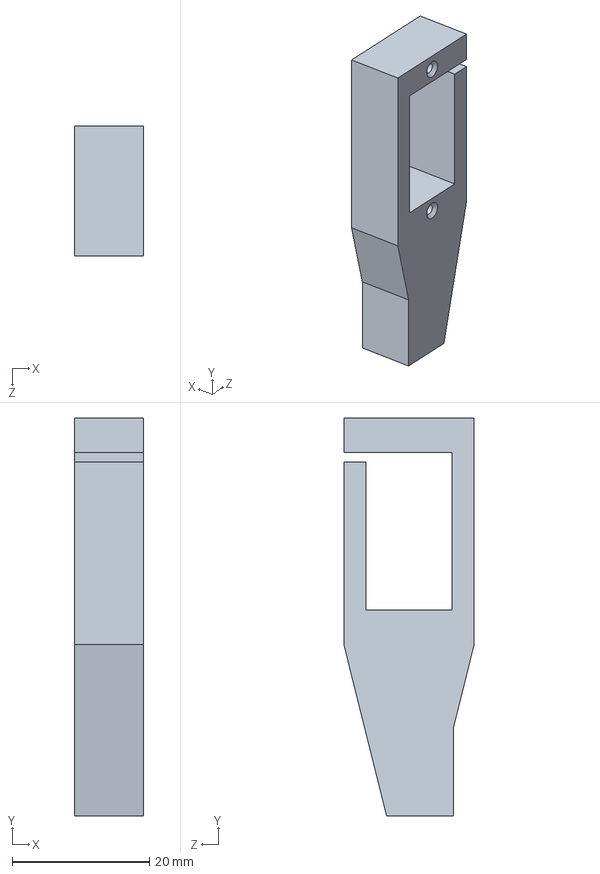
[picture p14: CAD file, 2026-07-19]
hardware/cad/Foot.SLDPRT
10.0 x 58.0 x 19.0 mm

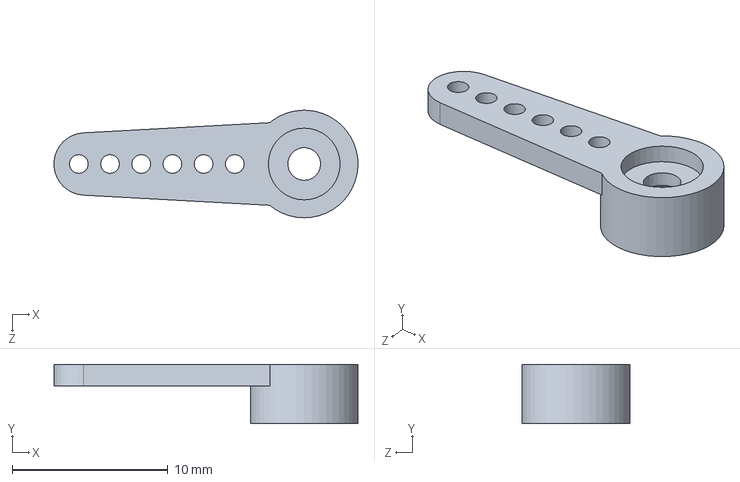
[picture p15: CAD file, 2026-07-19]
hardware/cad/SG90 - Arm.SLDPRT
19.5 x 3.80 x 6.90 mm

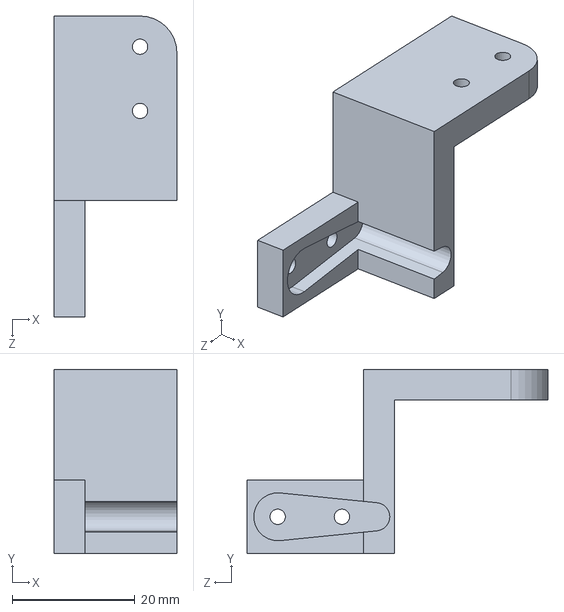
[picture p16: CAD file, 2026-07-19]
hardware/cad/Femur.SLDPRT
20.0 x 30.0 x 49.0 mm

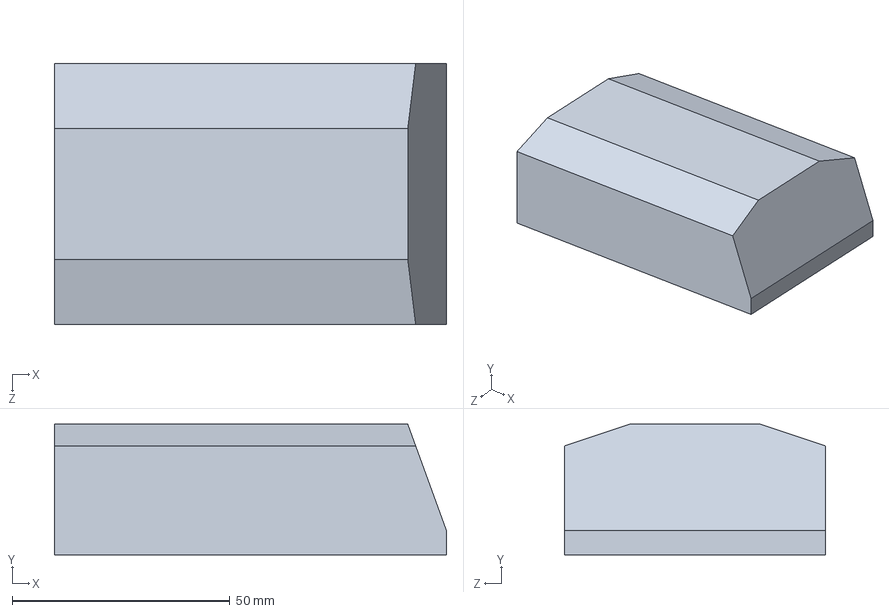
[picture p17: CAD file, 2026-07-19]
hardware/cad/Hermit Top.SLDPRT
90.0 x 30.0 x 60.0 mm

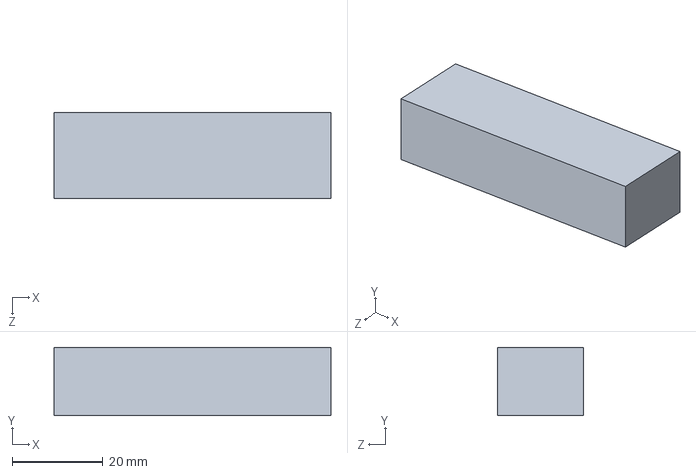
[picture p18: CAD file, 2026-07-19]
hardware/cad/battery.SLDPRT
61.0 x 15.0 x 19.0 mm

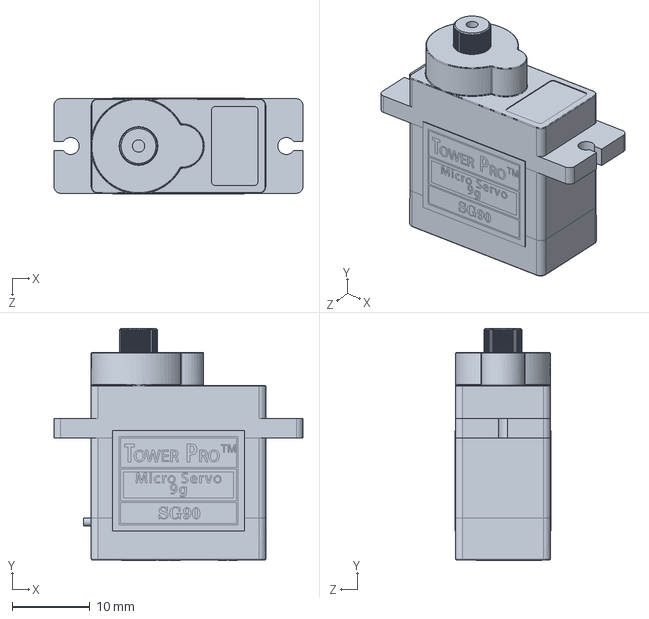
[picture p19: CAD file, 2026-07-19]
hardware/cad/SG90 - Micro Servo 9g - Tower Pro.SLDPRT
32.1 x 30.0 x 12.4 mm

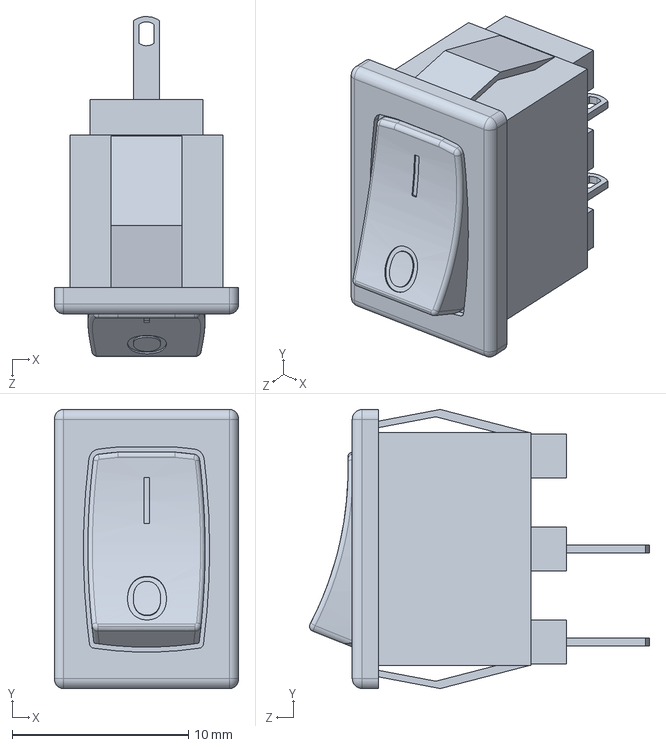
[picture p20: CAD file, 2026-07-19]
hardware/cad/rocker switch KCD11.SLDPRT
10.5 x 15.8 x 19.3 mm

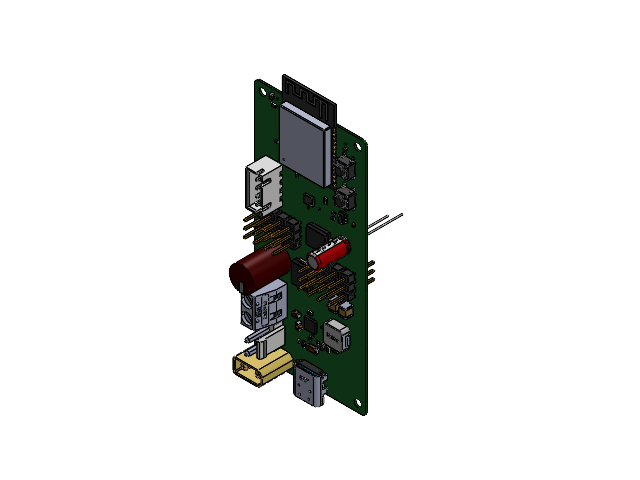
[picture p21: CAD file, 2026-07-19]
hardware/cad/PCB_V1.SLDASM
9075865888.step
9075853888.step
9075864544.step x 2
5x11x2x0.5.step
5x11x2x0.5-0.step
9075864928.step
base.step
body.step
logo.step
terminals.step
IC_BODY.step
IC_LEG.step x 3
circle.step
Diodes Incorporated.step
IC_LEG_MIR4.step x 2
9075851344.step
9075854992.step
9075864736.step
9075851008.step x 2
9075850432.step x 2
Extruded.step x 2
Extruded-1.step x 2
Extruded-2.step x 2
9075850048.step
9075867040.step
9075867808.step
9075853072.step
9075866848.step
9075855328.step
9075867232.step
pin.step
base-3.step
USB4085-GF-A_PART2.step
USB4085-GF-A_PART1_1.step
Part27_USB4085-GF-A_1.step
BxB-XH-A_04.step
_TSW-103-22-G-S_body.step x 8
_T-1S6-15-TSW-1-22-3-S.step x 8
Samtec Logo.step x 8
BxP-VH_2.step
pin-4.step x 2
terminals-5.step x 5
body-6.step x 5
logo-7.step x 5
9075865504.step x 2
9075863968.step
9075868000.step x 2
9075854560.step
9075855520.step
9075866464.step
9075867424.step
9075867616.step
9075850288.step
9075866656.step
9075852784.step x 2

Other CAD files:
hardware/cad/Hermit_V1.1 Purple.SLDPRT

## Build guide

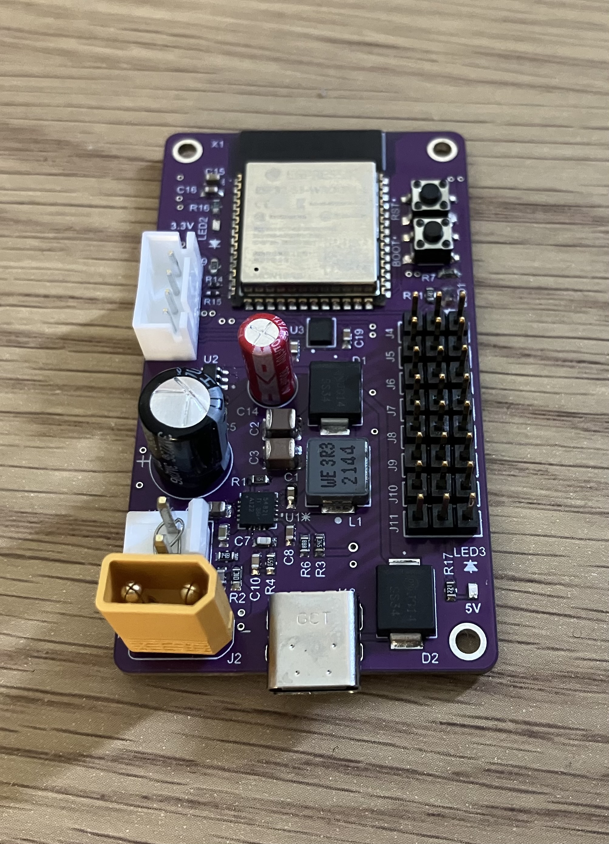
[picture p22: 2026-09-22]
hardware/pcb/v2/Hermit_V2_AssembledPCB.jpeg

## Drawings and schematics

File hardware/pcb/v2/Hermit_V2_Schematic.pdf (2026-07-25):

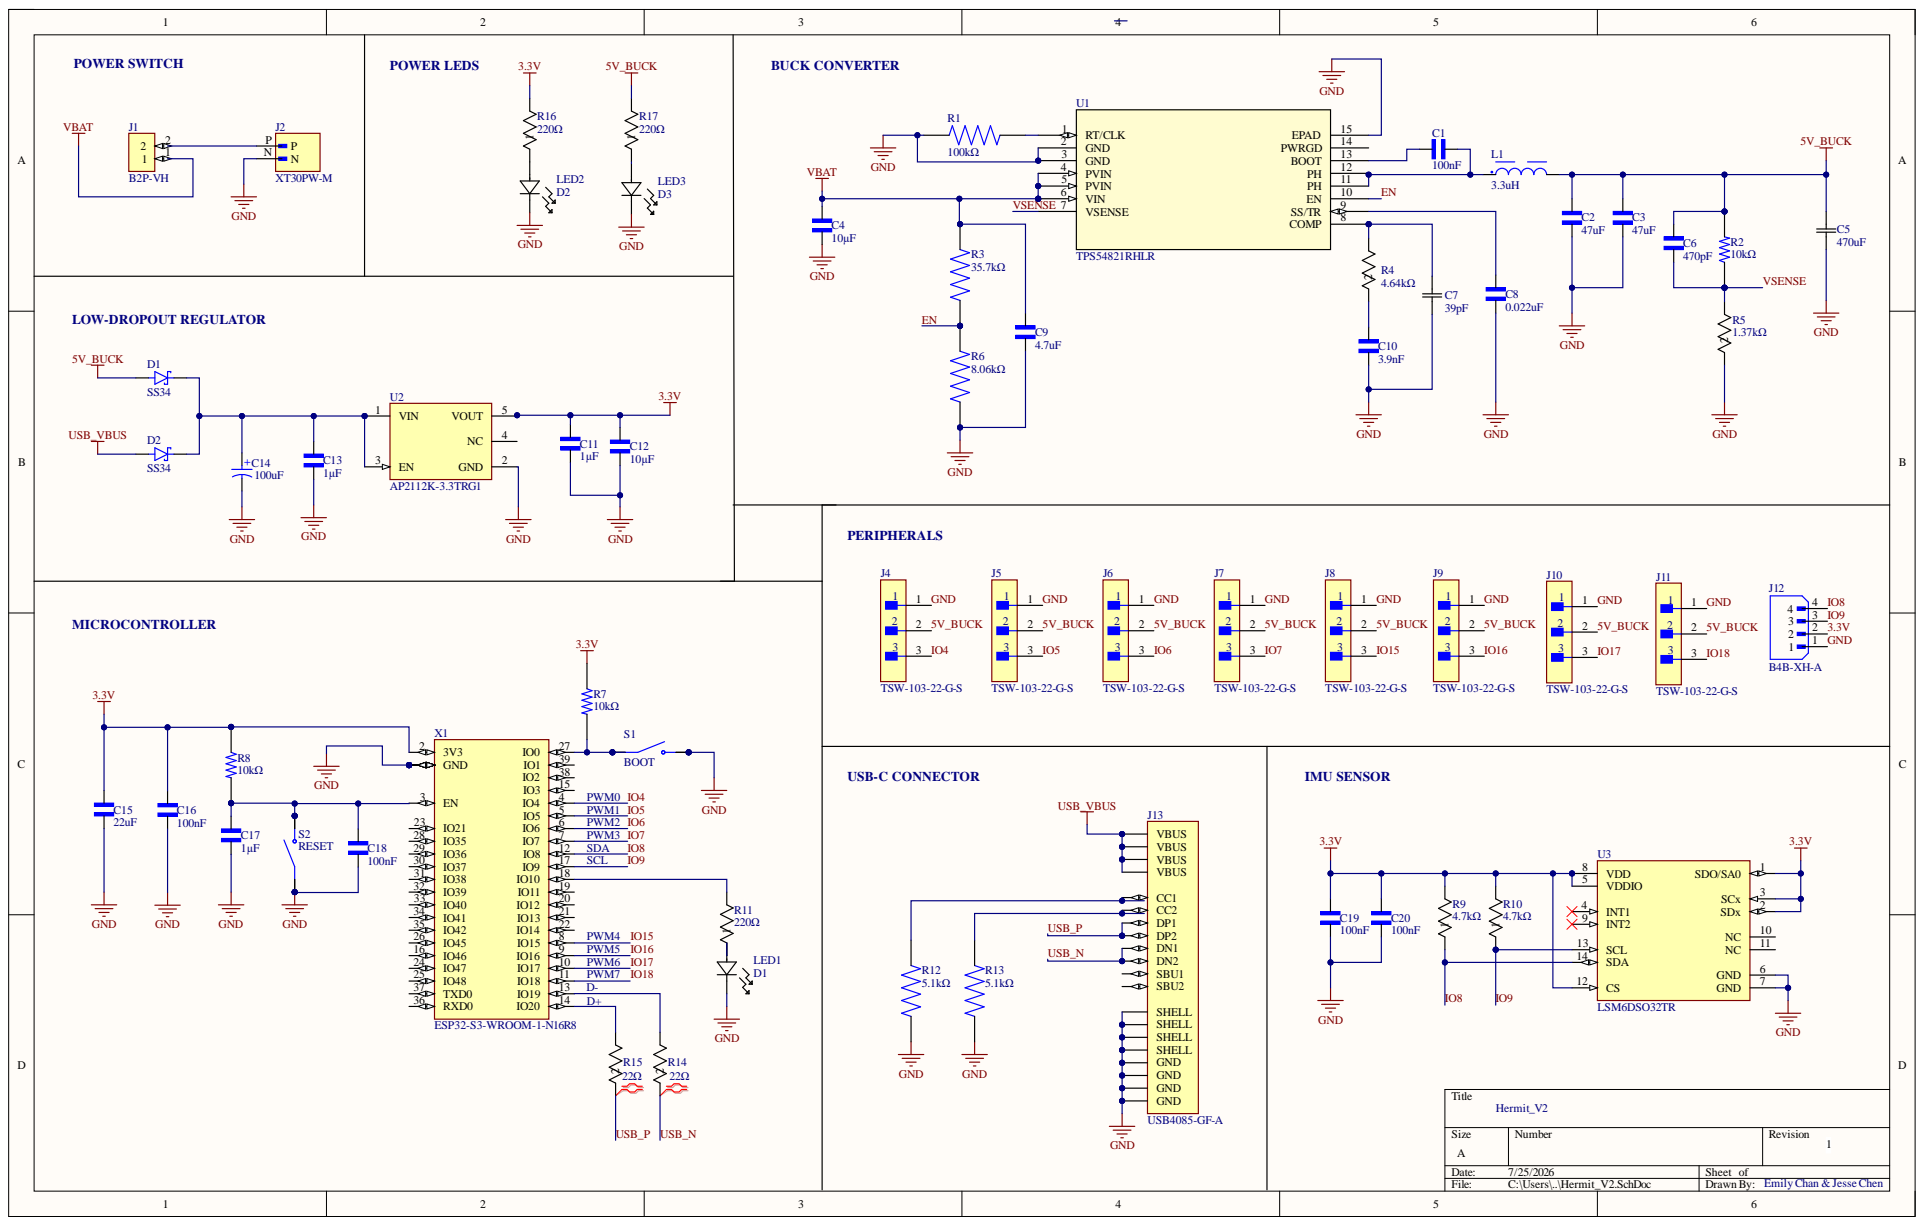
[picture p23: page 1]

Si z e | Num b er | Revi s i on

e : 7/25/ 20 2 6 | Sheet of
Fi l e : C : \U ser s \..\ Her m i t_V2.S chDo c | D rawn By: E m i ly Chan & Jes se Chen

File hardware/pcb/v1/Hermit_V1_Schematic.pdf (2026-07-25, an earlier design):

# NSE C9

1B2P-

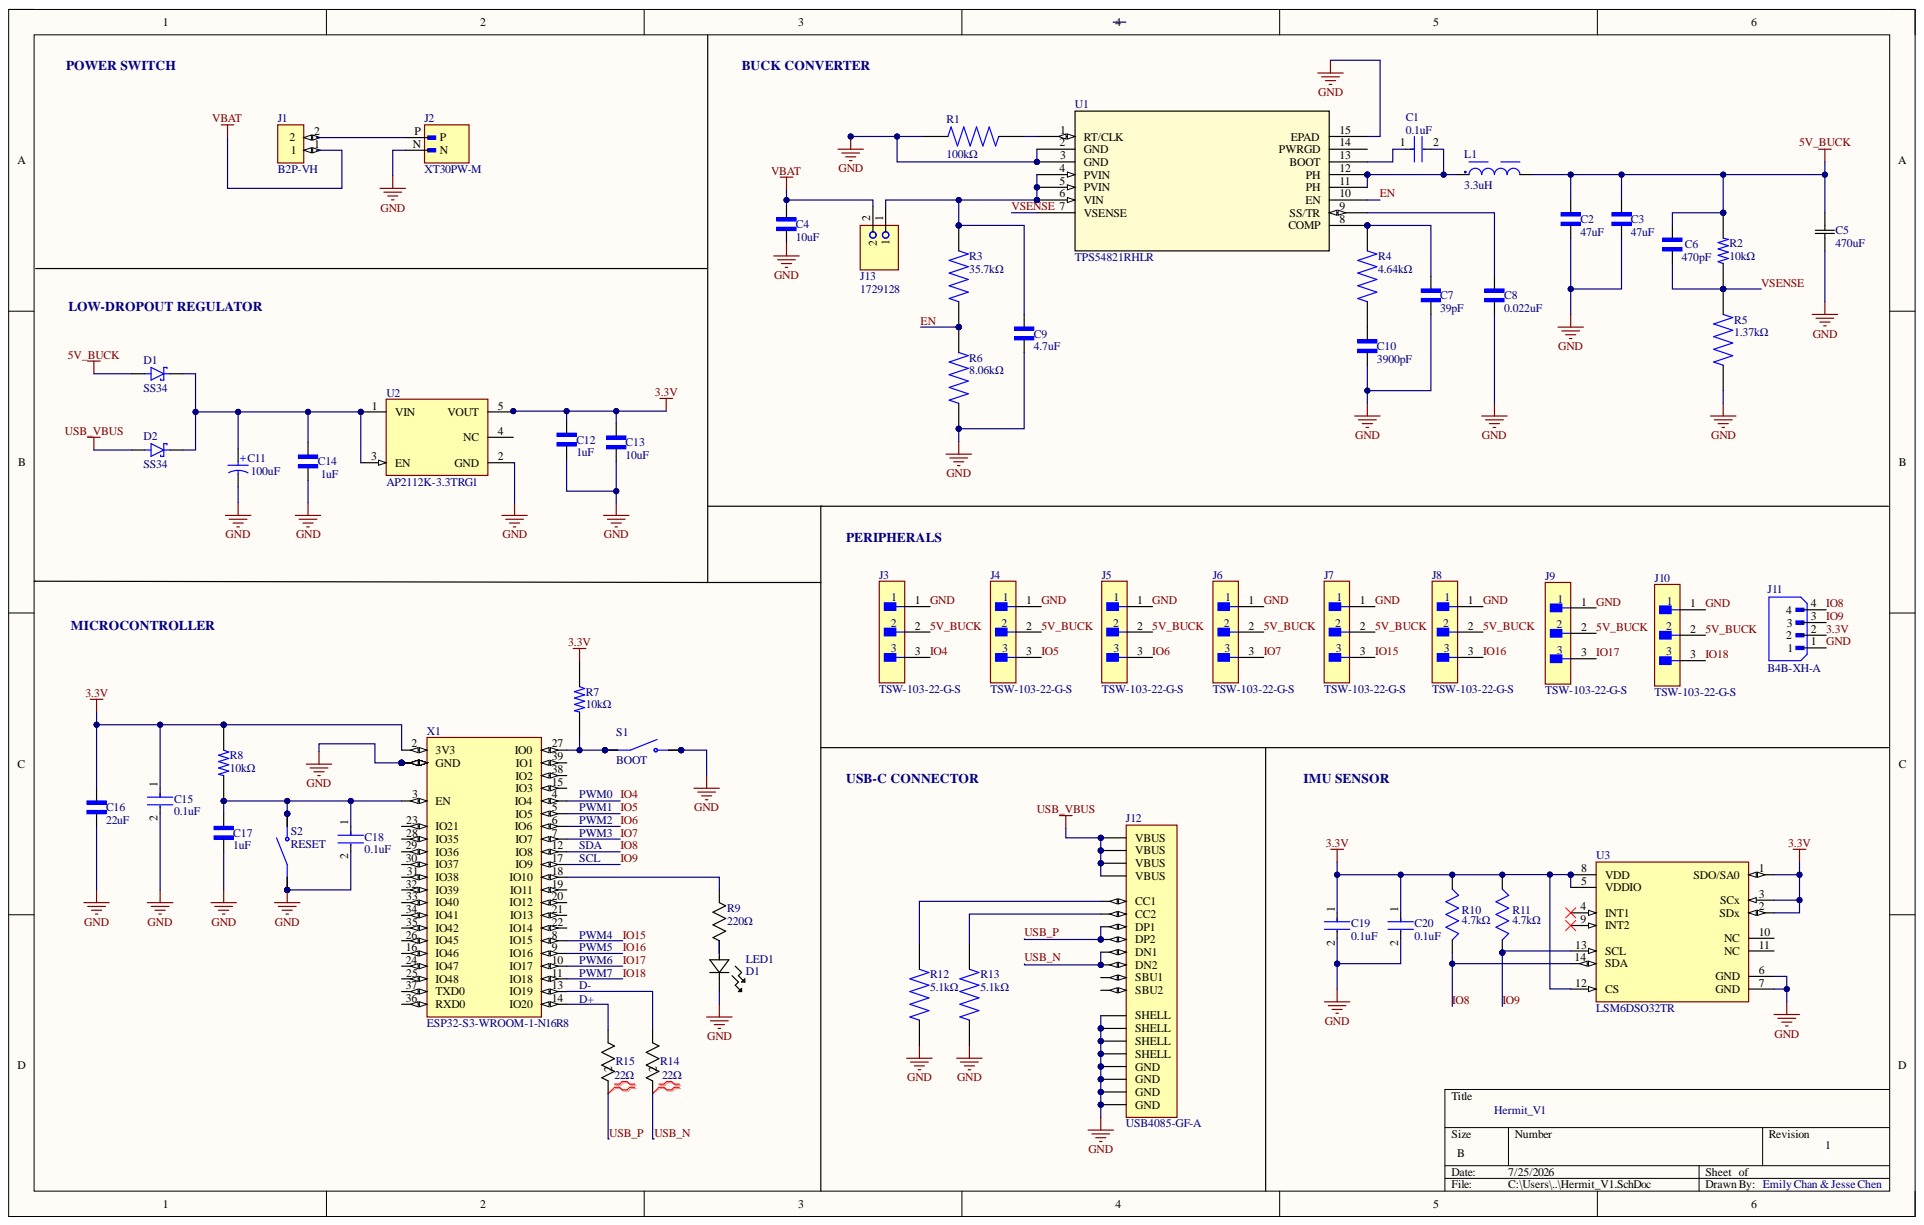
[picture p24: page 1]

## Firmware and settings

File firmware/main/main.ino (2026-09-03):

#include <WiFi.h>
#include <WebServer.h>
#include <ESP32Servo.h>
#include <Wire.h>
#include <Adafruit_GFX.h>
#include <Adafruit_SSD1306.h>
#include "movement-sequences.hpp"
#include "face-bitmaps.hpp"
#include "web.hpp"

// ======================================================================
// TYPES
// ======================================================================

// A command in that travels through the queue
struct Command {
  MovementState state;
  bool          held;
};

// One row of the string -> state lookup table used by the serial CLI and web /cmd
struct CommandEntry {
  const char*   str;
  MovementState state;
};

// One row of the state -> face bitmap lookup table used on state transitions
struct FaceEntry {
  MovementState        state;
  const unsigned char* bitmap;
};

// ======================================================================
// CONFIGURATION
// ======================================================================

// ---- WiFi Access Point ----
const char*    AP_SSID         = "HermitCrab";
const char*    AP_PASS         = "12345678";
const bool     AP_HIDDEN       = false;
const uint8_t  AP_MAX_CONN     = 2;
const uint32_t HOLD_TIMEOUT_MS = 600;  // Held-gait watchdog window (ms)

// ---- Servos ----
const uint8_t  OPERATING_FREQ = 50;    // Servo PWM frequency (Hz)
const uint16_t MIN_PULSE      = 833;   // 0deg   pulse width (us) - trimmed from 500
const uint16_t MAX_PULSE      = 2167;  // 180deg pulse width (us) - trimmed from 2500

const int INTERP_TICK_MS = 20;         // 50 Hz interpolator tick (1000/OPERATING_FREQ)
const int MAX_SPEED      = 600;        // Max angular velocity (deg/s)
                                       // (lower = smoother, higher = snappier)

// Label:                     R1  R2  L1  L2  R4  R3  L3  L4
const uint8_t servoPins[8] = {13, 14, 23, 16, 17, 18, 19, 33};

// ---- OLED Face Display ----
const uint16_t OLED_WIDTH    = 128;
const uint16_t OLED_HEIGHT   = 64;
const uint8_t  OLED_I2C_ADDR = 0x3C;
const int8_t   OLED_RESET    = -1;

const uint8_t I2C_SDA = 21;
const uint8_t I2C_SCL = 22;

// ======================================================================
// LOOKUP TABLES
// ======================================================================

// String -> state. Drives both the serial CLI and the web /cmd endpoint
static const CommandEntry COMMAND_TABLE[] = {
  { "stop",   STATE_IDLE     },
  { "rest",   STATE_REST     },
  { "stand",  STATE_STAND    },
  { "walk",   STATE_FORWARD  },
  { "back",   STATE_BACKWARD },
  { "left",   STATE_LEFT     },
  { "right",  STATE_RIGHT    },
  { "wave",   STATE_WAVE     },
  { "dance",  STATE_DANCE    },
  { "swim",   STATE_SWIM     },
  { "point",  STATE_POINT    },
  { "pushup", STATE_PUSHUP   },
  { "bow",    STATE_BOW      },
  { "cute",   STATE_CUTE     },
  { "freaky", STATE_FREAKY   },
  { "worm",   STATE_WORM     },
  { "shake",  STATE_SHAKE    },
  { "shrug",  STATE_SHRUG    },
  { "dead",   STATE_DEAD     },
  { "crab",   STATE_CRAB     },
};
static const int COMMAND_TABLE_SIZE = sizeof(COMMAND_TABLE) / sizeof(COMMAND_TABLE[0]);

// State -> face bitmap. nullptr entries draw no face
static const FaceEntry FACE_TABLE[] = {
  { STATE_IDLE,     nullptr           },
  { STATE_STAND,    epd_bitmap_stand  },
  { STATE_REST,     epd_bitmap_rest   },
  { STATE_FORWARD,  epd_bitmap_walk   },
  { STATE_BACKWARD, epd_bitmap_walk   },
  { STATE_LEFT,     epd_bitmap_walk   },
  { STATE_RIGHT,    epd_bitmap_walk   },
  { STATE_WAVE,     epd_bitmap_wave   },
  { STATE_DANCE,    epd_bitmap_dance  },
  { STATE_SWIM,     epd_bitmap_swim   },
  { STATE_POINT,    epd_bitmap_point  },
  { STATE_PUSHUP,   epd_bitmap_pushup },
  { STATE_BOW,      epd_bitmap_bow    },
  { STATE_CUTE,     epd_bitmap_cute   },
  { STATE_FREAKY,   epd_bitmap_freaky },
  { STATE_WORM,     epd_bitmap_worm   },
  { STATE_SHAKE,    epd_bitmap_shake  },
  { STATE_SHRUG,    epd_bitmap_shrug  },
  { STATE_DEAD,     epd_bitmap_dead   },
  { STATE_CRAB,     epd_bitmap_crab   },
};
static const int FACE_TABLE_SIZE = sizeof(FACE_TABLE) / sizeof(FACE_TABLE[0]);

// ======================================================================
// STATE
// ======================================================================

// ---- WiFi Access Point ----
IPAddress AP_IP(192, 168, 0, 1);
IPAddress AP_GATEWAY(192, 168, 0, 1);
IPAddress AP_SUBNET(255, 255, 255, 0);
WebServer server(80);

// ---- Servos ----
Servo          servos[8];
float          servoPos[8];              // Where each servo is now (deg)
volatile float servoTarget[8];           // Where each servo is headed (deg)
int8_t         servoSubtrim[8] = {0};    // Per-servo trim (deg), runtime-tunable
                                         // via the "subtrim" serial command

// ---- Movement ----
volatile MovementState currentCommand = STATE_IDLE;
QueueHandle_t          commandQueue;

volatile bool          holdWatchdog      = false;  // Armed by a held command
volatile unsigned long lastHoldRefreshMs = 0;

// ---- OLED Face Display ----
Adafruit_SSD1306  display(OLED_WIDTH, OLED_HEIGHT, &Wire, OLED_RESET);
SemaphoreHandle_t displayMutex;

volatile MovementState lastDisplayedState = STATE_IDLE;

// ---- Serial CLI ----
char commandBuffer[64];
byte bufferPos = 0;

// ======================================================================
// PROTOTYPES
// ======================================================================

// ---- Tasks ----
void webServerTask(void* param);
void serialTask(void* param);
void motionTask(void* param);
void interpolatorTask(void* param);

// ---- Servo Write Path ----
void setServoTarget(uint8_t channel, int angle);
void setServoImmediate(uint8_t channel, int angle);
void writeServoHardware(uint8_t channel, float pos);

// ---- Command Queue + Input ----
void        submitCommand(MovementState state, bool held);
bool        pollCommandQueue();
void        waitForCommand();
bool        pressingCheck(MovementState expectedState, int ms);
bool        interruptibleDelay(int ms);
bool        parseMovementCommand(const char* str, MovementState& out);
const char* commandName(MovementState state);
void        handleSubtrimCommand(const char* buf);
void        checkSerial();

// ---- Network + Web ----
void setupWiFi();
void setupWebServer();
void handleRoot();
void handleCmd();
void handleMotor();
void handleStatus();

// ---- OLED ----
void setupOLED();
void drawFace(const unsigned char* bitmap);
void showFace(MovementState state);

// ======================================================================
// SETUP
// ======================================================================

void setup() {

  // FreeRTOS primitives
  displayMutex = xSemaphoreCreateMutex();
  commandQueue = xQueueCreate(1, sizeof(Command));

  // Serial communication
  Serial.begin(115200);
  delay(100);

  Serial.println("Hermit Crab booting up...");

  // I2C + OLED
  Wire.begin(I2C_SDA, I2C_SCL);
  setupOLED();
  drawFace(epd_bitmap_idle);

  // Reserve all 4 LEDC hardware timers for stable PWM
  ESP32PWM::allocateTimer(0);
  ESP32PWM::allocateTimer(1);
  ESP32PWM::allocateTimer(2);
  ESP32PWM::allocateTimer(3);

  // Servo init with the 180deg window inside the 270deg servo pulse range
  for (int i = 0; i < 8; i++) {
    servos[i].setPeriodHertz(OPERATING_FREQ);
    servos[i].attach(servoPins[i], MIN_PULSE, MAX_PULSE);
  }
  delay(10);

  // Snap every servo to rest (90deg)
  for (int i = 0; i < 8; i++) {
    setServoImmediate(i, 90);
    delay(5);
  }

  // WiFi access point + HTTP server
  setupWiFi();
  setupWebServer();

  // Core 0 - I/O tasks
  xTaskCreatePinnedToCore(webServerTask, "WebServer", 4096, NULL, 1, NULL, 0);
  xTaskCreatePinnedToCore(serialTask, "Serial", 2048, NULL, 1, NULL, 0);

  // Core 1 - movement tasks
  xTaskCreatePinnedToCore(interpolatorTask, "Interp", 4096, NULL, 3, NULL, 1);
  xTaskCreatePinnedToCore(motionTask, "Motion", 8192, NULL, 2, NULL, 1);

  // Startup message
  Serial.println("-----------------------------------");
  Serial.println("    HERMIT CRAB WIFI + SERIAL      ");
  Serial.println("-----------------------------------");
  Serial.print  (" Web UI: http://");
  Serial.println(AP_IP);
  Serial.println();
  Serial.print  ("Interpolator: 50 Hz tick, max ");
  Serial.print  (MAX_SPEED);
  Serial.println(" deg/s");
  Serial.println();
  Serial.println("Serial Commands:");
  Serial.println("  rest, stand, walk, back, left, right");
  Serial.println("  wave, dance, swim, point, pushup");
  Serial.println("  bow, cute, freaky, worm, shake");
  Serial.println("  shrug, dead, crab, stop");
  Serial.println();
  Serial.println("  subtrim               (show values)");
  Serial.println("  subtrim <m> <v>       (set motor m)");
  Serial.println("  subtrim reset / save");
  Serial.println();
  Serial.println("  <m> <angle>           (direct motor)");
  Serial.println("  all <angle>           (all motors)");
  Serial.println("-----------------------------------");
}

// ======================================================================
// LOOP
// ======================================================================

void loop() {
  vTaskDelete(NULL); // Arduino loop unused; all work runs in FreeRTOS tasks
}

// ======================================================================
// TASKS
// ======================================================================

// Core 0: services the web server client poll loop
void webServerTask(void* param) {
  for (;;) {
    server.handleClient();
    vTaskDelay(pdMS_TO_TICKS(5));
  }
}

// Core 0: drains the serial CLI
void serialTask(void* param) {
  for (;;) {
    checkSerial();
    vTaskDelay(pdMS_TO_TICKS(10));
  }
}

// Core 1: ramps every servo toward its target at MAX_SPEED deg/s instead of
// snapping — the only task allowed to write servo hardware
void interpolatorTask(void* param) {
  for (;;) {
    float maxStep = (float)MAX_SPEED * INTERP_TICK_MS / 1000.0f;  // Max degrees movable per tick

    // Advance all 8 servos towards target
    for (int i = 0; i < 8; i++) {
      float target = servoTarget[i];
      float diff   = target - servoPos[i];
      if (diff != 0.0f) {
        if      (diff >  maxStep) servoPos[i] += maxStep;
        else if (diff < -maxStep) servoPos[i] -= maxStep;
        else                      servoPos[i]  = target; 
        writeServoHardware(i, servoPos[i]);
      }
    }
    vTaskDelay(pdMS_TO_TICKS(INTERP_TICK_MS));
  }
}

// Core 1: the movement brain. Pulls commands off the queue, drives the face,
// and dispatches the current state to its pose/gait sequence
void motionTask(void* param) {
  for (;;) {
    
    pollCommandQueue();

    // On state transition: update face + announce over serial
    if (currentCommand != lastDisplayedState) {
      showFace(currentCommand);
      Serial.print("State: ");
      Serial.println(commandName(currentCommand));
      lastDisplayedState = currentCommand;
    }

    // Dispatch: state -> sequence table lookup
    const Sequence* seq = lookupSequence(currentCommand);
    if (seq != nullptr) {
      if (seq->isGait) {
        // Gait movement (WALK/BACK/LEFT/RIGHT) - abort returns to stand pose
        if (!playGaitCycle(*seq, currentCommand) && currentCommand == STATE_IDLE) {
          drawFace(epd_bitmap_stand);
        }
      } 
      else if (playPose(*seq)) {
        if (seq->sticky) {
          // Sticky pose (STAND/REST/DEAD) - sleep until a new command arrives
          waitForCommand();
        }
        else {
          // Animated pose - return to stand pose upon full completion
          currentCommand = STATE_IDLE;
          if (seq->standAtEnd) drawFace(epd_bitmap_stand);
        }
      }
    }
    vTaskDelay(pdMS_TO_TICKS(1));
  }
}

// ======================================================================
// OLED FACE DISPLAY
// ======================================================================

void setupOLED() {
  if (!display.begin(SSD1306_SWITCHCAPVCC, OLED_I2C_ADDR)) {
    Serial.println("SSD1306 not found — check wiring and I2C address");
    return; // Robot still runs without the display
  }
  display.clearDisplay();
  display.display();
  Serial.println("OLED initialized");
}

// Looks up the face for a state and draws it
void showFace(MovementState state) {
  const unsigned char* bitmap = nullptr;
  for (int i = 0; i < FACE_TABLE_SIZE; i++) {
    if (FACE_TABLE[i].state == state) {
      bitmap = FACE_TABLE[i].bitmap;
      break;
    }
  }
  if (bitmap == nullptr) return; // No-op
  drawFace(bitmap);
}

// Display a face bitmap (mutex-guarded)
void drawFace(const unsigned char* bitmap) {
  xSemaphoreTake(displayMutex, portMAX_DELAY);
  display.clearDisplay();
  display.drawBitmap(0, 0, bitmap, OLED_WIDTH, OLED_HEIGHT, SSD1306_WHITE);
  display.display();
  xSemaphoreGive(displayMutex);
}

// ======================================================================
// WIFI SETUP
// ======================================================================

void setupWiFi() {
  WiFi.mode(WIFI_AP);
  WiFi.softAPConfig(AP_IP, AP_GATEWAY, AP_SUBNET);
  WiFi.softAP(AP_SSID, AP_PASS, 1, AP_HIDDEN, AP_MAX_CONN);
  Serial.print("AP started — SSID: ");
  Serial.print(AP_SSID);
  Serial.print("  IP: ");
  Serial.println(WiFi.softAPIP());
}

// ======================================================================
// WEB SERVER SETUP & HANDLERS
// ======================================================================

void setupWebServer() {
  server.on("/",       handleRoot);
  server.on("/cmd",    handleCmd);
  server.on("/motor",  handleMotor);
  server.on("/status", handleStatus);
  server.onNotFound(handleRoot);
  server.begin();
  Serial.println("HTTP server started on port 80");
}

// GET /
void handleRoot() {
  server.send_P(200, "text/html", INDEX_HTML);
}

// GET /cmd?c=<command> — accepts any COMMAND_TABLE string and adds it to the queue
void handleCmd() {
  if (!server.hasArg("c")) {
    server.send(400, "text/plain", "missing arg");
    return;
  }
  String cmdStr = server.arg("c");
  MovementState parsed;
  if (parseMovementCommand(cmdStr.c_str(), parsed)) {
    const Sequence* seq = lookupSequence(parsed);
    submitCommand(parsed, seq != nullptr && seq->isGait);
    server.send(200, "text/plain", cmdStr);
  }
  else {
    server.send(400, "text/plain", "unknown");
  }
}

// GET /motor?i=<0-7>&a=<0-180> — direct single-servo control
void handleMotor() {
  if (!server.hasArg("i") || !server.hasArg("a")) {
    server.send(400, "text/plain", "missing args");
    return;
  }
  int idx   = server.arg("i").toInt();
  int angle = server.arg("a").toInt();
  if (idx < 0 || idx > 7 || angle < 0 || angle > 180) {
    server.send(400, "text/plain", "out of range");
    return;
  }
  submitCommand(STATE_IDLE, false);
  setServoTarget(idx, angle);
  server.send(200, "text/plain", "ok");
}

// GET /status — lightweight JSON snapshot (state + live servo positions)
// Intended as a hook for future Python scripting
void handleStatus() {
  MovementState state = currentCommand;
  String json = "{\"state\":";
  json += String((int)state);
  json += ",\"name\":\"";
  json += commandName(state);
  json += "\",\"pos\":[";
  for (int i = 0; i < 8; i++) {
    json += String((int)(servoPos[i] + 0.5f));
    if (i < 7) json += ",";
  }
  json += "]}";
  server.send(200, "application/json", json);
}

// ======================================================================
// HELPER FUNCTIONS
// ======================================================================

// String -> state via COMMAND_TABLE, returns false on no match
bool parseMovementCommand(const char* str, MovementState& out) {
  for (int i = 0; i < COMMAND_TABLE_SIZE; i++) {
    if (strcmp(str, COMMAND_TABLE[i].str) == 0) {
      out = COMMAND_TABLE[i].state;
      return true;
    }
  }
  return false;
}

// Reverse lookup: state → command string, for transition announcements
const char* commandName(MovementState state) {
  for (int i = 0; i < COMMAND_TABLE_SIZE; i++) {
    if (COMMAND_TABLE[i].state == state) return COMMAND_TABLE[i].str;
  }
  return "?";
}

// Handles all "subtrim ..." command variants: save / reset / set / show
void handleSubtrimCommand(const char* buf) {
  if (strcmp(buf, "subtrim save") == 0) {
    Serial.println("Copy this into the code:");
    Serial.print("int8_t servoSubtrim[8] = {");
    for (int i = 0; i < 8; i++) {
      Serial.print(servoSubtrim[i]);
      if (i < 7) Serial.print(", ");
    }
    Serial.println("};");
  } 
  else if (strcmp(buf, "subtrim reset") == 0) {
    for (int i = 0; i < 8; i++) servoSubtrim[i] = 0;
    Serial.println("All subtrim values reset to 0");
  } 
  else if (strncmp(buf, "subtrim ", 8) == 0) {
    int trimMotor, trimValue;
    if (sscanf(buf + 8, "%d %d", &trimMotor, &trimValue) == 2) {
      if (trimMotor >= 0 && trimMotor < 8 && trimValue >= -90 && trimValue <= 90) {
        servoSubtrim[trimMotor] = (int8_t)trimValue;
        Serial.print("Motor "); Serial.print(trimMotor);
        Serial.print(" subtrim -> ");
        if (trimValue >= 0) Serial.print("+");
        Serial.println(trimValue);
      } 
      else {
        Serial.println("Invalid — motor: 0-7, value: -90 to +90");
      }
    }
  } 
  else {
    Serial.println("Subtrim values:");
    for (int i = 0; i < 8; i++) {
      Serial.print("  Motor "); Serial.print(i); Serial.print(": ");
      if (servoSubtrim[i] >= 0) Serial.print("+");
      Serial.println(servoSubtrim[i]);
    }
  }
}

// Sets where a servo should head (safe from any task)
void setServoTarget(uint8_t channel, int angle) {
  if (channel >= 8) return;
  servoTarget[channel] = (float)constrain(angle, 0, 180);
}

// Boot-only snap that bypasses interpolation (not safe once tasks are running)
void setServoImmediate(uint8_t channel, int angle) {
  if (channel >= 8) return;
  float a = (float)constrain(angle, 0, 180);
  servoPos[channel]    = a;
  servoTarget[channel] = a;
  writeServoHardware(channel, a);
}

// Maps angle + subtrim to a pulse and drives the servo (only called by interpolator task)
void writeServoHardware(uint8_t channel, float pos) {
  int adjusted = constrain((int)(pos + 0.5f) + servoSubtrim[channel], 0, 180);
  int pulseUs  = map(adjusted, 0, 180, MIN_PULSE, MAX_PULSE);
  servos[channel].writeMicroseconds(pulseUs);
}

// Reads and processes any pending serial bytes mid-animation
void checkSerial() {
  while (Serial.available()) {
    char c = Serial.read();

    // Terminator: parse the accumulated line
    if (c == '\n' || c == '\r') {
      if (bufferPos > 0) {
        commandBuffer[bufferPos] = '\0';
        bufferPos = 0;

        // Parse command and perform action
        MovementState parsed;
        if (parseMovementCommand(commandBuffer, parsed)) {
          submitCommand(parsed, false);
          Serial.print("Command: "); Serial.println(commandBuffer);
        } 
        else if (strncmp(commandBuffer, "subtrim", 7) == 0) {
          handleSubtrimCommand(commandBuffer);
        } 
        else if (strncmp(commandBuffer, "all ", 4) == 0) {
          int angle;
          if (sscanf(commandBuffer + 4, "%d", &angle) == 1) {
            for (int i = 0; i < 8; i++) setServoTarget(i, angle);
            Serial.print("All servos -> "); Serial.println(angle);
          }
        } 
        else {
          int motorNum, angle;
          if (sscanf(commandBuffer, "%d %d", &motorNum, &angle) == 2) {
            if (motorNum >= 0 && motorNum < 8) {
              setServoTarget(motorNum, angle);
              Serial.print("Servo "); Serial.print(motorNum);
              Serial.print(" -> "); Serial.println(angle);
            } else {
              Serial.println("Invalid motor number (0-7)");
            }
          } 
          else {
            Serial.print("Unknown command: "); Serial.println(commandBuffer);
          }
        }
      }
    } 
    // Otherwise accumulate, if buffer space remains
    else if (bufferPos < sizeof(commandBuffer) - 1) {
      commandBuffer[bufferPos++] = c;
    }
  }
}

// Enqueues a command and overwrites so the newest command always wins
void submitCommand(MovementState state, bool held) {
  Command cmd = { state, held };
  xQueueOverwrite(commandQueue, &cmd);
}

// Applies a dequeued command to currentCommand + watchdog state
static void applyCommand(const Command& incoming) {
  currentCommand = incoming.state;
  holdWatchdog   = incoming.held;
  if (incoming.held) lastHoldRefreshMs = millis();
}

// Dequeues one command if present and returns true, updating currentCommand + watchdog state
bool pollCommandQueue() {
  Command incoming;
  if (xQueueReceive(commandQueue, &incoming, 0) != pdTRUE) return false;
  applyCommand(incoming);
  return true;
}

// Blocks the calling task until a command arrives, then applies it
void waitForCommand() {
  Command incoming;
  xQueueReceive(commandQueue, &incoming, portMAX_DELAY);
  applyCommand(incoming);
}

// Interruptible sleep for animated poses (wave, dance, etc.)
// Returns true if the full duration elapsed, false if currentCommand changed
bool interruptibleDelay(int ms) {
  MovementState stateAtStart = currentCommand;
  unsigned long start = millis();
  while (millis() - start < ms) {
    pollCommandQueue();
    if (currentCommand != stateAtStart) return false; // Any change aborts
    vTaskDelay(pdMS_TO_TICKS(1));
  }
  return true;
}
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

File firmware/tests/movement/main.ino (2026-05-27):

#include <ESP32Servo.h>
#include "movement-sequences.h"

// ======================================================================
// CONFIGURATION
// ======================================================================

// ---- Hardware ----
const int OPERATING_FREQ = 50;                                // Hz
const int servoPins[8]  = {13, 14, 15, 16, 17, 18, 19, 21};   // Index: 0  1  2  3   4   5   6   7

// ---- MG90D Pulse Calibration ----
// Full travel: 500–2500 µs → 2000 µs span for 270°
// Trimming to center 180°: (45° / 270°) * 2000 µs ≈ 333 µs per side
const int MIN_PULSE = 833;    // 500  + 333
const int MAX_PULSE = 2167;   // 2500 - 333

// ---- Tuning ----
int frameDelay        = 100;  // ms between gait frames
int motorCurrentDelay = 5;    // ms between servo writes (prevents brownout)

// ---- Subtrim ----
int8_t servoSubtrim[8] = {0, 0, 0, 0, 0, 0, 0, 0};

// ======================================================================
// STATE
// ======================================================================

Servo servos[8];
String currentCommand = "";
char   command_buffer[64];
byte   buffer_pos = 0;

// ======================================================================
// PROTOTYPES
// ======================================================================

void setServoAngle(uint8_t channel, int angle);
bool pressingCheck(String cmd, int ms);

// ======================================================================
// Setup
// ======================================================================
void setup() {
  Serial.begin(115200); // Baud rate for Serial Monitor
  while (!Serial);

  Serial.println("Hermit Crab booting up...");

  // Reserve all 4 LEDC hardware timers so that the Servo library can guarantee stable pulses for PWM
  ESP32PWM::allocateTimer(0);
  ESP32PWM::allocateTimer(1);
  ESP32PWM::allocateTimer(2);
  ESP32PWM::allocateTimer(3);

  // Servo init with 270° calibration
  for (int i = 0; i < 8; i++) {
    servos[i].setPeriodHertz(OPERATING_FREQ);
    servos[i].attach(servoPins[i], MIN_PULSE, MAX_PULSE);
  }
  delay(10);

  Serial.println("-----------------------------------");
  Serial.println("    HERMIT CRAB SERIAL INTERFACE   ");
  Serial.println("-----------------------------------");
  Serial.println("Static Pose Commands:");
  Serial.println("  rest, stand");
  Serial.println();
  Serial.println("Animated Pose Commands:");
  Serial.println("  wave, dance, swim, point, pushup");
  Serial.println("  bow, cute, freaky, worm, shake");
  Serial.println("  shrug, dead, crab");
  Serial.println();
  Serial.println("Movement Commands:");
  Serial.println("  walk, back, left, right");
  Serial.println();
  Serial.println("Subtrim Commands:");
  Serial.println("  subtrim               (show values)");
  Serial.println("  subtrim <m> <v>       (set motor m to value v)");
  Serial.println("  subtrim reset         (reset all to 0)");
  Serial.println("  subtrim save          (print array for code)");
  Serial.println();
  Serial.println("Direct Motor Control:");
  Serial.println("  <m> <angle>           (set motor m)");
  Serial.println("  all <angle>           (set all motors)");
  Serial.println();
  Serial.println("Other:");
  Serial.println("  stop");
  Serial.println("-----------------------------------");
}

// ======================================================================
// Loop
// ======================================================================
void loop() {

  if (currentCommand != "") {
    String cmd = currentCommand;
    if      (cmd == "forward")  runWalkPose();
    else if (cmd == "backward") runWalkBackward();
    else if (cmd == "left")     runTurnLeft();
    else if (cmd == "right")    runTurnRight();
    else if (cmd == "rest")     runRestPose();
    else if (cmd == "stand")    runStandPose();
    else if (cmd == "wave")     runWavePose();
    else if (cmd == "dance")    runDancePose();
    else if (cmd == "swim")     runSwimPose();
    else if (cmd == "point")    runPointPose();
    else if (cmd == "pushup")   runPushupPose();
    else if (cmd == "bow")      runBowPose();
    else if (cmd == "cute")     runCutePose();
    else if (cmd == "freaky")   runFreakyPose();
    else if (cmd == "worm")     runWormPose();
    else if (cmd == "shake")    runShakePose();
    else if (cmd == "shrug")    runShrugPose();
    else if (cmd == "dead")     runDeadPose();
    else if (cmd == "crab")     runCrabPose();
  }

  // ----- Serial CLI -----
  if (Serial.available()) {
    char c = Serial.read();

    // End of command
    if (c == '\n' || c == '\r') {

      // Reset command buffer
      if (buffer_pos > 0) {
        command_buffer[buffer_pos] = '\0';
        buffer_pos = 0;
        int motorNum, angle;

        // Stop command
        if (strcmp(command_buffer, "stop") == 0) {
          currentCommand = "";
          runStandPose();
          Serial.println("STOPPED");
        }

        // Static poses
        else if (strcmp(command_buffer, "rest")  == 0) {
          currentCommand = "";
          runRestPose();
        }
        else if (strcmp(command_buffer, "stand") == 0) {
          currentCommand = "";
          runStandPose();
        }

        // Animated poses
        else if (strcmp(command_buffer, "wave") == 0) { currentCommand = "wave";   runWavePose(); }
        else if (strcmp(command_buffer, "dance") == 0) { currentCommand = "dance";  runDancePose(); }
        else if (strcmp(command_buffer, "swim") == 0) { currentCommand = "swim";   runSwimPose(); }
        else if (strcmp(command_buffer, "point") == 0) { currentCommand = "point";  runPointPose(); }
        else if (strcmp(command_buffer, "pushup") == 0) { currentCommand = "pushup"; runPushupPose(); }
        else if (strcmp(command_buffer, "bow") == 0) { currentCommand = "bow";    runBowPose(); }
        else if (strcmp(command_buffer, "cute") == 0) { currentCommand = "cute";   runCutePose(); }
        else if (strcmp(command_buffer, "freaky") == 0) { currentCommand = "freaky"; runFreakyPose(); }
        else if (strcmp(command_buffer, "worm") == 0) { currentCommand = "worm";   runWormPose(); }
        else if (strcmp(command_buffer, "shake") == 0) { currentCommand = "shake";  runShakePose(); }
        else if (strcmp(command_buffer, "shrug") == 0) { currentCommand = "shrug";  runShrugPose(); }
        else if (strcmp(command_buffer, "dead") == 0) { currentCommand = "dead";   runDeadPose(); }
        else if (strcmp(command_buffer, "crab") == 0) { currentCommand = "crab";   runCrabPose(); }

        // Movement commands
        else if (strcmp(command_buffer, "walk") == 0) { currentCommand = "forward"; runWalkPose(); }
        else if (strcmp(command_buffer, "back") == 0) { currentCommand = "backward"; runWalkBackward(); }
        else if (strcmp(command_buffer, "left") == 0) { currentCommand = "left"; runTurnLeft(); }
        else if (strcmp(command_buffer, "right") == 0) { currentCommand = "right"; runTurnRight(); }
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

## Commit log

2026-05-23 Removed OLED code to prevent I2C hang during initial testing
    [motor-tester.ino]
2026-05-27 Implemented separatE MG90D motor tester project
2026-05-31 Hermit PCB Schematic Revision 1
2026-06-03 Fixed motor pin assignment and added stand/rest pose to state machine dispatch loop
    [mg90d-servo-test.ino]
2026-06-03 Added PCB 3D step file
    [HermitCrab.step]
2026-06-05 Added Hermit V1 schematic
    [HermitCrab.step]
2026-06-05 Added Hermit V1 schematic w/o extra Altium info
2026-06-05 Added ESP32 access point web server
2026-06-07 Added Hermit V1 PCB step file
    [Hermit_V1.step]
2026-06-12 Added gerber files
    [Hermit_V1_Copper_Signal_1.gbr, Hermit_V1_Copper_Signal_2.gbr, Hermit_V1_Copper_Signal_Bot.gbr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]
2026-06-12 Added zipped gerber files
2026-06-12 Added Hermit V1 BOM
    [Hermit_V1_BOM.xlsx]
2026-06-13 Cleaned up formatting
    [Hermit_V1_PCB.step]
2026-06-14 Changed OLED pin assignment
2026-06-14 Added finalized V1 PCB files
    [Hermit_V1.step, Hermit_V1_BOM.xlsx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]
2026-06-23 Smoothed direct motor control and stop web command behaviour
2026-07-16 Deleted V0 directory
    [HermitCrab.step]
2026-07-17 docs: version 1 PCB files and documentation
    [Hermit V1_BOM.xlsx, Hermit_V1_Model.step]
2026-07-17 docs: design calculations for PCB development
2026-07-18 fix: only motionTask transitions currentCommand to IDLE
2026-07-19 feat: add interpolator task and keyframe/sequence data model
    Replaces the old per-pose switch statement with a data-driven Sequence/Keyframe model. The interpolatorTask runs on Core 1 at 50 Hz and is the sole writer of servo hardware, eliminating the need for a servo mutex.
2026-07-19 docs: cleaned up code comments and servo pin assignment
2026-07-19 docs: added Hermit_V2 pcb schematic
2026-07-19 docs: renamed directory from Hermit_V1 to v1
    [Hermit V1_BOM.xlsx, Hermit_V1_Model.step]
2026-07-19 Add V1 CAD files.
    [Femur.SLDPRT, Foot.SLDPRT, Hermit Chassis.SLDPRT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]
2026-07-19 docs: reorganize hardware files
    [Femur.SLDPRT, Foot.SLDPRT, Hermit Chassis.SLDPRT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]
2026-07-24 docs: update V2 PCB schematic
2026-07-25 docs: add 2D and 3D PCB layout png files
2026-07-25 docs: revise README with ESP32-S3 and demo video
    Updated microcontroller model and added video demo link.
2026-07-25 docs: add README to pcb/v2 and update 3D layout
2026-07-25 docs: add Altium Designer documentation and images
    [Hermit_V1_Model.step]
2026-07-29 docs: update pcb files
2026-07-31 docs: add BOM excel files
    [Hermit_V1_BOM.xlsx, Hermit_V2_BOM.xlsx]
2026-08-11 docs: add cad prototype png
2026-09-19 docs: add jpeg of assembled V2 PCB
2026-09-22 feat(tests): add servo test for v2 pcb verification
2026-09-25 docs(pcb): add note to changes in v2
